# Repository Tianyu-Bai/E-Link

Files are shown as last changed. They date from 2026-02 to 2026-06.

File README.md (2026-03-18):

<div class="lang-en" markdown="1">

<div class="github-only" align="center" style="margin: 40px 0;">
  <a href="https://tianyu-bai.github.io/E-Link">
    
  </a>
  <p style="margin-top: 20px; font-size: 3.5em; font-weight: bold; color: #1e293b;">
    <i>🚀 Click the banner above to interactively rotate, zoom, and explore the internal routing! 🚀</i>
  </p>
</div>

<div align="center">
  <h1 style="border-bottom: none; margin-bottom: 5px; color: #60a5fa; font-size: 2em;">🚀 E-Link(256)</h1>
  
  
</div>

<div align="center" style="margin-top: 15px;">
    
    
    
    
    
  </div>

<br />

<div align="center" class="nav-badges">
  
  
  
  
  
  
</div>

<div align="center">
  <br />
  ELINK-256 Assembly Demo GIF
</div>

<span id="en-overview"></span>
## 📖 Overview

**E-Link** (Elastomer Interconnection-based connector) is an open-source, miniature pedestal connector system based on elastomer interconnection. It provides a robust, scalable interface for flexible neural probes, specifically engineered for chronic applications in freely moving animals.
<div align="center">
 <br>
 E-Link(256) Exploded View
 <p style="margin-top: 5px; font-size: 0.95em; color: #3b82f6;">
   <b>Mating Dynamics (left) and Structural Breakdown (right) of the E-Link(256) </b>
 </p>
</div>

> [!IMPORTANT]
> **Interactive 3D View Available!** > GitHub doesn't support 3D models natively. <a href="https://tianyu-bai.github.io/E-Link">**Click here to interactively rotate, zoom, and explode this assembly directly in your browser!**</a>
---

> [!NOTE]
> **Key Innovation:** The system integrates two high-density PCBs, an anisotropic elastomeric contact interface, and a lightweight pedestal housing into a fully integrated, headstage-ready solution.

---

<span id="en-specs"></span>
### 📊 Quick Specifications

<div align="center">
 <table style="margin-left: auto; margin-right: auto; width: 80%; text-align: center; border-collapse: collapse; border: 1px solid #e1e4e8;">
   <thead>
     <tr style="background-color: #f6f8fa; border-bottom: 2px solid #e1e4e8;">
       <th style="padding: 10px; border: 1px solid #e1e4e8;">Specification</th>
       <th style="padding: 10px; border: 1px solid #e1e4e8;">E-Link(256)_V1.0</th>
     </tr>
   </thead>
   <tbody>
     <tr>
       <td style="padding: 8px; border: 1px solid #e1e4e8;"><b>Channel Count</b></td>
       <td style="padding: 8px; border: 1px solid #e1e4e8;">128 or 256 Channels (Single/Dual SPI Port support)</td>
     </tr>
     <tr>
       <td style="padding: 8px; border: 1px solid #e1e4e8;"><b>Total Mass</b></td>
       <td style="padding: 8px; border: 1px solid #e1e4e8;">6.6 g (with housing)<br>2.8 g (without housing)</td>
     </tr>
     <tr>
       <td style="padding: 8px; border: 1px solid #e1e4e8;"><b>Interconnect Type</b></td>
       <td style="padding: 8px; border: 1px solid #e1e4e8;">Solderless Anisotropic Elastomer</td>
     </tr>
     <tr>
       <td style="padding: 8px; border: 1px solid #e1e4e8;"><b>Compatible Acquisition System</b></td>
       <td style="padding: 8px; border: 1px solid #e1e4e8;">Intan Recording Controller (512ch/1024ch)<br>Open-Ephys DAQ box<br>NeuroNexus Smartbox<br>OmniPlex DAQ box</td>
     </tr>
     <tr>
       <td style="padding: 8px; border: 1px solid #e1e4e8;"><b>Housing Material</b></td>
       <td style="padding: 8px; border: 1px solid #e1e4e8;">3D-Printed PEEK / Surgical Grade Resin</td>
     </tr>
   </tbody>
 </table>
</div>

---

<span id="en-features"></span>
## ✨ Key Features

* **⚡ 256-Channel High-Density & Scalable Interface**<br>
  Compact pedestal footprint supporting 256-ch acquisition. The elastomer-based design offers a clear scaling roadmap (up to 1024-ch) without increasing physical size or surgical overhead.

* **🔌 Zero-Force "Soft" Interconnect**<br>
  By replacing rigid pins with Anisotropic Conductive Elastomer, the system shifts from "insertion" to "compression." This "Gentle yet Firm" philosophy eliminates common failure modes like "bent or broken pins" from the physical level.

* **🎯 Self-Aligning & High Tolerance**<br>
  Features a high-precision mechanical guidance structure with "Structural Redundancy." It naturally forgives minor manual misalignments, ensuring reliable contact with simple rotation — no microscopic alignment required.

* **🛠️ Modular Maintenance & On-Demand Assembly**<br>
  Separable "Sandwich" structure (Housing, Adapter PCB, Headstage). Allows independent replacement of damaged modules and supports on-demand chip soldering (e.g., populating 1, 2, or 4 Intan chips) to save research costs.

* **🪶 Detachable Active Electronics for Unburdened Rest**<br>
  During non-recording periods, the heavy headstage and active electronics can be easily separated from the implanted pedestal. This leaves only a minimal, lightweight passive interface on the skull, significantly 
  reducing the physical payload on the animal and promoting natural behavior between sessions.

* **🐭 Optimized for Chronic In-Vivo Research**<br>
  Ultra-lightweight core (2.8g without housing) and low-profile design. Fully compatible with commutators, ensuring natural behavior and cable management during long-term recording in freely moving animals.

* **🧪 Surgical-Grade Integration & Anatomical Adaptation**<br>
  Features textured sidewalls for superior adhesion with dental cement/UV resin. The base curvature can be customized to match the specific cranial profiles of different animals during 3D printing, ensuring a rock-solid isolation chamber that protects delicate probes from fluids and scratching.
  
<div align="center">
 ELINK-256 Animation GIF
</div>

---

<span id="en-components"></span>
## 🧩 System Components

<div align="center">
 <table border="1" style="border-collapse: collapse; width: 90%; text-align: center;">
   <thead>
     <tr style="background-color: #f2f2f2;">
       <th>Component</th>
       <th>Description</th>
     </tr>
   </thead>
   <tbody>
     <tr>
       <td><b>Pedestal Housing</b></td>
       <td>3D-printed/machined pedestal providing structural support and cranial fixation</td>
     </tr>
     <tr>
       <td><b>Customized 256Ch Headstage</b></td>
       <td>Form-factor optimized recording interface for high-density 128/256-channel signal acquisition</td>
     </tr>
     <tr>
       <td><b>Foam Washer</b></td>
       <td>Provides compliant compression to ensure uniform electrical contact across the elastomeric interface</td>
     </tr>
     <tr>
       <td><b>Adapter PCB</b></td>
       <td>High-density 4-layer PCB for routing signals from thin-film probes to headstage ball array pattern</td>
     </tr>
     <tr>
       <td><b>Surgical Cap</b></td>
       <td>Protective enclosure preserving electrical and mechanical integrity throughout chronic experiments</td>
     </tr>
   </tbody>
 </table>
</div>

---

<span id="en-bom"></span>
### 🛠 Bill of Materials (BOM) of the headstage

<div align="center">
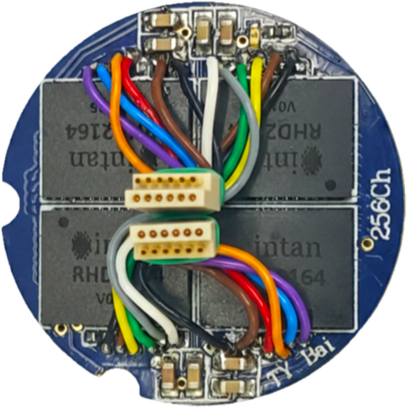
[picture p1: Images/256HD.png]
256Ch Headstage PCBA Assembly
  
  <p style="margin-top: 5px; font-size: 0.9em; color: #64748b;">
    <b>Assembled 256-Channel Headstage (Top View)</b>
  </p>
</div>

<div align="center">
  4-Layer PCB Stackup Explosion
  <p style="margin-top: 5px; font-size: 0.9em; color: #64748b;">
    <b> 4-Layer Routing Structure (Top to Bottom)</b>
  </p>
</div>

> [!TIP]
> **🔍 Inspect the PCB Layers Up Close:** > Want to zoom in on the components or the BGA routing? <a href="https://tianyu-bai.github.io/E-Link">**Visit our interactive website**</a> to view the 3D PCBA model and examine the high-density layout!
<div align="center">
 <table style="margin-left: auto; margin-right: auto; width: 90%; text-align: center; border-collapse: collapse; border: 1px solid #e1e4e8;">
   <thead>
     <tr style="background-color: #f6f8fa; border-bottom: 2px solid #e1e4e8;">
       <th style="padding: 10px; border: 1px solid #e1e4e8; text-align: center;">Component</th>
       <th style="padding: 10px; border: 1px solid #e1e4e8; text-align: center;">Description</th>
       <th style="padding: 10px; border: 1px solid #e1e4e8; text-align: center;">Qty</th>
       <th style="padding: 10px; border: 1px solid #e1e4e8; text-align: center;">Package</th>
       <th style="padding: 10px; border: 1px solid #e1e4e8; text-align: center;">Notes</th>
     </tr>
   </thead>
   <tbody>
     <tr>
       <td style="padding: 8px; border: 1px solid #e1e4e8; text-align: center;"><b>Amplifier IC</b></td>
       <td style="padding: 8px; border: 1px solid #e1e4e8; text-align: center;">Intan RHD2164</td>
       <td style="padding: 8px; border: 1px solid #e1e4e8; text-align: center;">4</td>
       <td style="padding: 8px; border: 1px solid #e1e4e8; text-align: center;">BGA</td>
       <td style="padding: 8px; border: 1px solid #e1e4e8; text-align: center;"><b>Critical:</b> Ensure correct orientation</td>
     </tr>
     <tr>
       <td style="padding: 8px; border: 1px solid #e1e4e8; text-align: center;"><b>SPI Connector</b></td>
       <td style="padding: 8px; border: 1px solid #e1e4e8; text-align: center;">Omnetics A7621</td>
       <td style="padding: 8px; border: 1px solid #e1e4e8; text-align: center;">2</td>
       <td style="padding: 8px; border: 1px solid #e1e4e8; text-align: center;">-</td>
       <td style="padding: 8px; border: 1px solid #e1e4e8; text-align: center;">12-wire cable harness (32 AWG)</td>
     </tr>
     <tr>
       <td style="padding: 8px; border: 1px solid #e1e4e8; text-align: center;"><b>Resistors</b></td>
       <td style="padding: 8px; border: 1px solid #e1e4e8; text-align: center;">Standard SMD</td>
       <td style="padding: 8px; border: 1px solid #e1e4e8; text-align: center;">7</td>
       <td style="padding: 8px; border: 1px solid #e1e4e8; text-align: center;">0402</td>
       <td style="padding: 8px; border: 1px solid #e1e4e8; text-align: center;">LVDS Configuration</td>
     </tr>
     <tr>
       <td style="padding: 8px; border: 1px solid #e1e4e8; text-align: center;"><b>Capacitors</b></td>
       <td style="padding: 8px; border: 1px solid #e1e4e8; text-align: center;">Standard SMD</td>
       <td style="padding: 8px; border: 1px solid #e1e4e8; text-align: center;">8</td>
       <td style="padding: 8px; border: 1px solid #e1e4e8; text-align: center;">0603</td>
       <td style="padding: 8px; border: 1px solid #e1e4e8; text-align: center;">LVDS Configuration</td>
     </tr>
     <tr>
       <td style="padding: 8px; border: 1px solid #e1e4e8; text-align: center;"><b>Power LED</b></td>
       <td style="padding: 8px; border: 1px solid #e1e4e8; text-align: center;">Green LED</td>
       <td style="padding: 8px; border: 1px solid #e1e4e8; text-align: center;">1</td>
       <td style="padding: 8px; border: 1px solid #e1e4e8; text-align: center;">0402</td>
       <td style="padding: 8px; border: 1px solid #e1e4e8; text-align: center;">Power Indicator</td>
     </tr>
     <tr>
       <td style="padding: 8px; border: 1px solid #e1e4e8; text-align: center;"><b>Solder Balls</b></td>
       <td style="padding: 8px; border: 1px solid #e1e4e8; text-align: center;">0.4 mm Lead-free</td>
       <td style="padding: 8px; border: 1px solid #e1e4e8; text-align: center;">~300</td>
       <td style="padding: 8px; border: 1px solid #e1e4e8; text-align: center;">-</td>
       <td style="padding: 8px; border: 1px solid #e1e4e8; text-align: center;">For BGA rework/assembly</td>
     </tr>
   </tbody>
 </table>
</div>

---

## 👥 Developers & Lab

This project is developed by the **MINE Lab** at Dartmouth College. 

* **Tianyu Bai** (Lead Designer) 
* **Gen Li, Ph.D.**
* **Hui Fang, Ph.D.** <a href="https://engineering.dartmouth.edu/community/faculty/hui-fang">

---

## 📄 Publication

This work is currently **under review** at the *IEEE Journal on Flexible Electronics (JFLEX)*.

The hardware designs and visual assets in this repository correspond directly to the system described in the submitted manuscript. To maintain the integrity of the peer-review process:

* **Full Citation**: A permanent link to the final paper will be updated here immediately upon formal acceptance.
* **Preprint/Full Paper**: *Coming Soon.*
  
* We welcome feedback and collaboration from the neuroengineering community!

* **Inquiries**: Thinking about using E-Link in your lab? We know setting up a new system can be tricky. If you have questions about the PCB design or 3D printing, drop us an email or open an issue. We'd love to help you get started!
  * **Email**: [<font color="#60a5fa">support@ephys.tech</font>](mailto:support@ephys.tech)
---

## 📑 Citation & DOI

If you utilize these designs, code, or assets in your research, please cite this repository using the persistent DOI provided by Zenodo:

**Current Reference:**
> T. Bai, et al., "E-Link GitHub Repository," v1.0, MINE Lab, Dartmouth College, 2026. 

---

<span id="en-downloads"></span>
## 🔗 Repository & Downloads

This project is fully open-source. Upon acceptance of the associated paper, the complete dataset comprising **PCB fabrication files (Gerber/NC Drill)**, **BOM**, and **Mechanical CAD** will be accessible via the link below.

<div align="center">
 <p><b>👇 Bookmark the repository for future downloads:</b></p>

<div align="center">
 
 
</div>
</div>

---

## 🤝 Acknowledgments

The developers gratefully acknowledge support from the **NIH (R01MH139342)** and the **Dartmouth PhD Innovation Fellowship**. 

Special thanks to the members of the **MINE Lab** and the **Thayer School of Engineering** for their technical support and feedback throughout the development of the E-Link (256) system.

---

## 📜 License

Copyright © 2026 Tianyu Bai 

This project is open-source and available under the **MIT License**. Click the badge below for full license details.

<div align="center">
 <a href="https://github.com/tianyu-bai/E-Link/blob/main/LICENSE">
   
 </a>
</div>

</div>

<div class="github-only">
  <br>
  <hr>
  <p align="center" style="font-size: 1.5em; font-weight: bold; margin: 20px 0;">
    👇 🇨🇳 Chinese Version / 中文版 👇
  </p>
  <hr>
  <br>
</div>

<div class="lang-zh" markdown="1">

<div class="github-only" align="center" style="margin: 40px 0;">
  <a href="https://tianyu-bai.github.io/E-Link">
    
  </a>
  <p style="margin-top: 20px; font-size: 1.5em; font-weight: bold; color: #1e293b;">
    <i>🚀 点击上方绿色横幅，在浏览器中亲自旋转、缩放，零死角探索 E-Link 细节！ 🚀</i>
  </p>
</div>

<div align="center">
  <h1 style="border-bottom: none; margin-bottom: 5px; color: #60a5fa; font-size: 2em;">🚀 E-Link(易链256)</h1>
  
  Typing SVG
</div>

<div align="center" style="margin-top: 15px;">
    
    
    
    
     
  </div>

  <br />

<div align="center" class="nav-badges">
  
  
  
  
  
  
</div>
  
<div align="center">
  <br />
  ELINK-256 组装演示 GIF
</div>

<span id="cn-overview"></span>
## 📖 概览

**E-Link易链**，是一款基于弹性体互连技术（Elastomer Interconnection）的开源微型基座连接系统。它为柔性神经探针提供了稳固且可扩展的接口，专为自由活动动物的长期慢性实验而优化设计

<div align="center">
  <br>
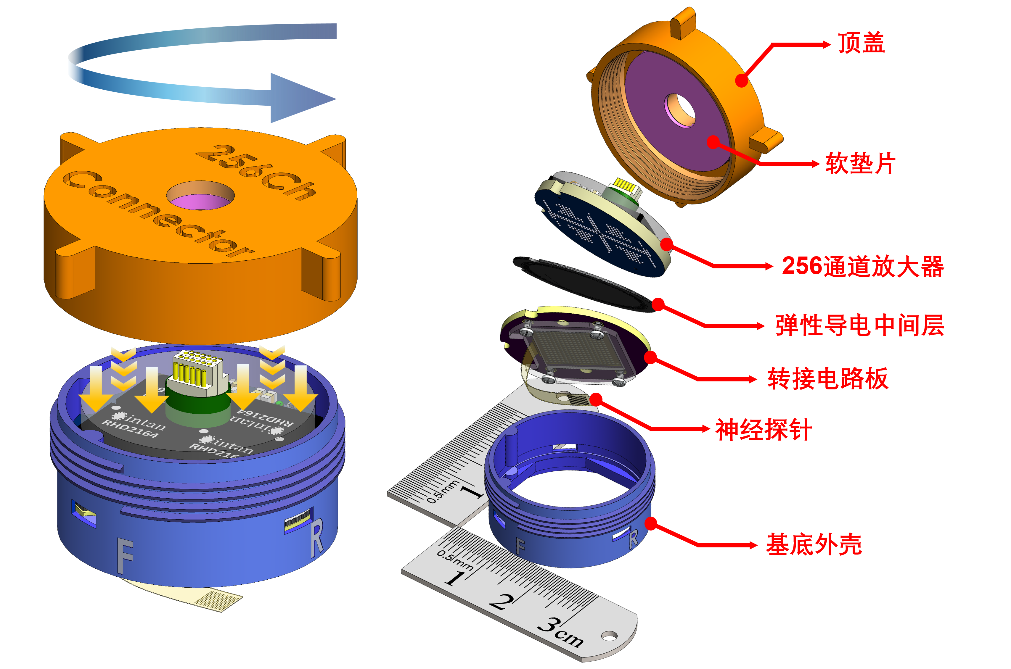
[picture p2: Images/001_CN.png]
E-Link_256 分解图
  
  <p style="margin-top: 5px; font-size: 0.95em; color: ##3b82f6;">
    <b>E-Link易链(256) 的插拔动态（左）和结构分解（右）</b>
  </p>
</div>

> [!IMPORTANT]
> **🎮 支持在线 3D 交互！** > GitHub 原生无法展示 3D 动效。<a href="https://tianyu-bai.github.io/E-Link">**请点击此处前往独立网站，在浏览器中亲自旋转、缩放并拆解此模型！**</a>
---

> [!NOTE]
> **核心创新：** 我们打造了一种完全一体化的 “即拧即用” 数据采集方案。该系统利用弹性导电介质连接高密度 PCB，并封装于轻量级基座中。其最大的突破在于实现了“零力插拔”。免去使用者用力插拔的动作，完美规避了多脚连接器常见的断针和弯针风险。

---

<span id="cn-specs"></span>
### 📊 规格参数

<div align="center">
  <table style="margin-left: auto; margin-right: auto; width: 80%; text-align: center; border-collapse: collapse; border: 1px solid #e1e4e8;">
    <thead>
      <tr style="background-color: #f6f8fa; border-bottom: 2px solid #e1e4e8;">
        <th style="padding: 10px; border: 1px solid #e1e4e8;">规格项目</th>
        <th style="padding: 10px; border: 1px solid #e1e4e8;">E-Link(256)_V1.0</th>
      </tr>
    </thead>
    <tbody>
      <tr>
        <td style="padding: 8px; border: 1px solid #e1e4e8;"><b>通道数</b></td>
        <td style="padding: 8px; border: 1px solid #e1e4e8;">128 或 256 通道 (支持单/双 SPI 端口)</td>
      </tr>
      <tr>
        <td style="padding: 8px; border: 1px solid #e1e4e8;"><b>总质量</b></td>
        <td style="padding: 8px; border: 1px solid #e1e4e8;">6.6 g (含外壳)<br>2.8 g (不含外壳)</td>
      </tr>
      <tr>
        <td style="padding: 8px; border: 1px solid #e1e4e8;"><b>互连类型</b></td>
        <td style="padding: 8px; border: 1px solid #e1e4e8;">免焊各向异性弹性体</td>
      </tr>
      <tr>
        <td style="padding: 8px; border: 1px solid #e1e4e8;"><b>兼容采集系统</b></td>
        <td style="padding: 8px; border: 1px solid #e1e4e8;">Intan Recording Controller (512ch/1024ch)<br>Open-Ephys DAQ box<br>NeuroNexus Smartbox<br>OmniPlex DAQ box</td>
      </tr>
      <tr>
        <td style="padding: 8px; border: 1px solid #e1e4e8;"><b>外壳材料</b></td>
        <td style="padding: 8px; border: 1px solid #e1e4e8;">3D 打印 PEEK / 手术级树脂</td>
      </tr>
    </tbody>
  </table>
</div>

---

<span id="cn-features"></span>
## ✨ 关键特性

* **⚡ 256通道高密度与可扩展接口**<br>
  在有限基座占地面积内实现256通道数据采集。得益于弹性体互连的高集成度，该系统提供了清晰的扩展路径（可达1024通道），且不会增加额外的手术复杂度。

* **🔌 零插拔力，以柔克刚**<br>
  利用各向异性导电弹性体取代传统刚性插针式连接器。通过“旋紧结构”将扭矩转化为均匀压力，从物理层面彻底规避了高密度连接器常见的断针、弯针等失效模式，让连接不再成为系统可靠性的短板。

* **🎯 自对准与高容错连接**<br>
  系统具备优异的机械限位与电气容错率。无需微米级精密对齐，只需简单旋紧即可实现稳定连接，极大降低了手动操作的难度和失败风险。

* **🛠️ 模块化维护与按需组装**<br>
  采用**“三明治”式分离结构**（外壳、适配板、放大器板）。支持损坏模块的单独更换，并允许根据实验通道需求灵活焊接单/多颗芯片，显著降低了科研成本与维护门槛。

* **🪶 电子模块即插即拆，释放动物头部负担**<br>
  在非记录期间，沉重的头件设备与有源电路可与底座快速分离，仅在颅骨留下极轻量的无源底座。这大幅减轻了动物的物理载荷，最大程度保障了动物在实验间隙的自然活动状态。

* **🐭 专为自由活动动物实验优化**<br>
  核心组件仅重 2.8g（移除上盖后）。低剖面设计完美适配换向器 (Commutator)，有效管理线缆并确保动物在长期慢性实验中的自然行为，提升动物福利。

* **🧪 手术级一体化与解剖结构适配**<br>
  侧壁纹理设计极大增强了与牙科水泥或UV树脂的附着力。基座底部的打印弧度可根据不同动物的头部曲线进行定制化调整，从而实现与颅骨的完美贴合，构建出全封闭的防护舱，有效阻隔体液侵蚀并抵抗动物抓挠。

<div align="center">
  ELINK-256 动画演示 GIF
</div>

---

<span id="cn-components"></span>
## 🧩 系统组件

<div align="center">
  <table border="1" style="border-collapse: collapse; width: 90%; text-align: center;">
    <thead>
      <tr style="background-color: #f2f2f2;">
        <th>组件</th>
        <th>描述</th>
      </tr>
    </thead>
    <tbody>
      <tr>
        <td><b>基座外壳</b></td>
        <td>3D 打印/机械加工的基座，提供结构支撑和颅骨固定</td>
      </tr>
      <tr>
        <td><b>定制化 256Ch 头部放大器</b></td>
        <td>针对高密度 128/256 通道信号采集优化的记录接口</td>
      </tr>
      <tr>
        <td><b>泡沫垫圈</b></td>
        <td>提供柔性压缩层，确保弹性导电基体上方的电气接触均匀</td>
      </tr>
      <tr>
        <td><b>转接PCB</b></td>
        <td>高密度 4 层 PCB，用于将信号从薄膜探针路由到放大器的球栅阵列图案转换</td>
      </tr>
      <tr>
        <td><b>手术保护盖</b></td>
        <td>保护性外壳，在长期慢性实验中保持电气和机械完整性</td>
      </tr>
    </tbody>
  </table>
</div>

---

<span id="cn-bom"></span>
### 🛠 放大器物料清单 (BOM)

<div align="center">
  256通道放大器组装实物图
  <p style="margin-top: 5px; font-size: 0.9em; color: #64748b;">
    <b>已组装的 256 通道前置放大器 (顶视图)</b>
  </p>
</div>

<div align="center">
  顶部4层电路板的设计爆炸动图
  <p style="margin-top: 5px; font-size: 0.9em; color: #64748b;">
    <b> 顶部4层电路板的设计爆炸动图 </b>
  </p>
</div>
    
> [!TIP]
> **🔍 在线放大查看 PCB 细节：** > 想要放大看清 0402 贴片或者 BGA 走线？<a href="https://tianyu-bai.github.io/E-Link">**访问我们的交互网站**</a>，即可在浏览器中与 3D 放大器模型互动，极其清晰地观察高密度布局！
<div align="center">
  <table style="margin-left: auto; margin-right: auto; width: 90%; text-align: center; border-collapse: collapse; border: 1px solid #e1e4e8;">
    <thead>
      <tr style="background-color: #f6f8fa; border-bottom: 2px solid #e1e4e8;">
        <th style="padding: 10px; border: 1px solid #e1e4e8; text-align: center;">组件</th>
        <th style="padding: 10px; border: 1px solid #e1e4e8; text-align: center;">描述</th>
        <th style="padding: 10px; border: 1px solid #e1e4e8; text-align: center;">数量</th>
        <th style="padding: 10px; border: 1px solid #e1e4e8; text-align: center;">封装</th>
        <th style="padding: 10px; border: 1px solid #e1e4e8; text-align: center;">备注</th>
      </tr>
    </thead>
    <tbody>
      <tr>
        <td style="padding: 8px; border: 1px solid #e1e4e8; text-align: center;"><b>放大器 IC</b></td>
        <td style="padding: 8px; border: 1px solid #e1e4e8; text-align: center;">Intan RHD2164</td>
        <td style="padding: 8px; border: 1px solid #e1e4e8; text-align: center;">4</td>
        <td style="padding: 8px; border: 1px solid #e1e4e8; text-align: center;">BGA</td>
        <td style="padding: 8px; border: 1px solid #e1e4e8; text-align: center;"><b>关键：</b> 确保方向正确</td>
      </tr>
      <tr>
        <td style="padding: 8px; border: 1px solid #e1e4e8; text-align: center;"><b>SPI 连接器</b></td>
        <td style="padding: 8px; border: 1px solid #e1e4e8; text-align: center;">Omnetics A7621</td>
        <td style="padding: 8px; border: 1px solid #e1e4e8; text-align: center;">2</td>
        <td style="padding: 8px; border: 1px solid #e1e4e8; text-align: center;">-</td>
        <td style="padding: 8px; border: 1px solid #e1e4e8; text-align: center;">12 线线束 (32 AWG)</td>
      </tr>
      <tr>
        <td style="padding: 8px; border: 1px solid #e1e4e8; text-align: center;"><b>电阻</b></td>
        <td style="padding: 8px; border: 1px solid #e1e4e8; text-align: center;">标准贴片</td>
        <td style="padding: 8px; border: 1px solid #e1e4e8; text-align: center;">7</td>
        <td style="padding: 8px; border: 1px solid #e1e4e8; text-align: center;">0402</td>
        <td style="padding: 8px; border: 1px solid #e1e4e8; text-align: center;">LVDS 配置</td>
      </tr>
      <tr>
        <td style="padding: 8px; border: 1px solid #e1e4e8; text-align: center;"><b>电容</b></td>
        <td style="padding: 8px; border: 1px solid #e1e4e8; text-align: center;">标准贴片</td>
        <td style="padding: 8px; border: 1px solid #e1e4e8; text-align: center;">8</td>
        <td style="padding: 8px; border: 1px solid #e1e4e8; text-align: center;">0603</td>
        <td style="padding: 8px; border: 1px solid #e1e4e8; text-align: center;">LVDS 配置</td>
      </tr>
      <tr>
        <td style="padding: 8px; border: 1px solid #e1e4e8; text-align: center;"><b>电源 LED</b></td>
        <td style="padding: 8px; border: 1px solid #e1e4e8; text-align: center;">绿色 LED</td>
        <td style="padding: 8px; border: 1px solid #e1e4e8; text-align: center;">1</td>
        <td style="padding: 8px; border: 1px solid #e1e4e8; text-align: center;">0402</td>
        <td style="padding: 8px; border: 1px solid #e1e4e8; text-align: center;">自检状态灯</td>
      </tr>
      <tr>
        <td style="padding: 8px; border: 1px solid #e1e4e8; text-align: center;"><b> 标注锡球 </b></td>
        <td style="padding: 8px; border: 1px solid #e1e4e8; text-align: center;">0.4 mm 无铅</td>
        <td style="padding: 8px; border: 1px solid #e1e4e8; text-align: center;">约300</td>
        <td style="padding: 8px; border: 1px solid #e1e4e8; text-align: center;">-</td>
        <td style="padding: 8px; border: 1px solid #e1e4e8; text-align: center;">用于 BGA 组装</td>
      </tr>
    </tbody>
  </table>
</div>

---

## 👥 开发者与实验室

本项目由达特茅斯学院 **Fang课题组** 开发。

* **白天宇** (主导研发及设计) 
* **李根**
* **方辉教授** <a href="https://engineering.dartmouth.edu/community/faculty/hui-fang">

---

## 📄 出版物

本工作目前正在 **IEEE Journal on Flexible Electronics (JFLEX)** 审稿中。

本仓库中的硬件设计和视觉资产直接对应于投稿中描述的系统。

* **完整引用**：正式录用后，最终论文的永久链接将立即在此处更新。
* **预印本/全文**：*即将推出。*
  
* 我们欢迎神经工程科研社区的反馈与合作！

* **咨询**：如需获取技术设计文件或有任何相关疑问，请邮件联系：
   * **技术支持**: [<font color="#60a5fa">support@ephys.tech</font>](mailto:support@ephys.tech)

---

## 📑 引用与 DOI

如果您在研究中使用了这些设计、代码或资产，请使用 Zenodo 提供的永久 DOI 引用本仓库：

**当前参考：**
> T. Bai, et al., "E-Link GitHub Repository," v1.0, MINE Lab, Dartmouth College, 2026. 

---

<span id="cn-downloads"></span>
## 🔗 仓库与下载

本项目完全开源。相关论文录用后，包含 **PCB 制造文件 (Gerber/NC Drill)** 和 **3D打印文件** 的完整数据集将通过以下链接提供访问。

<div align="center">
  <p><b>👇 欢迎收藏本仓库以便未来下载：</b></p>

<div align="center">
  
  
</div>
</div>

---

## 🤝 致谢

开发者衷心感谢 **美国国立卫生研究院 NIH R01MH139342** 和 **达特茅斯博士生创新奖学金 (Dartmouth PhD Innovation Fellowship)** 的支持。

特别感谢 **达特茅斯Thayer工学院** 的相关成员在易链系统开发过程中提供的技术支持和反馈。

---

## 📜 许可协议

版权所有 © 2026 Tianyu Bai 

本项目为开源硬件，在以下许可下可用。点击下方徽章查看完整许可详情。

* **硬件源文件** (KiCad/Gerbers/STL 文件)：在 **MIT 许可** 下授权。
* **文档、原理图 (PDF) 和图像**：在 **CC BY 4.0 国际许可** 下授权。

<div align="center">
  <a href="https://github.com/tianyu-bai/E-Link/blob/main/LICENSE">
    
  </a>
</div>

</div>

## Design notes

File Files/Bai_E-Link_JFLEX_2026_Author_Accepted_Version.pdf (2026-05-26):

IEEE JOURNAL ON FLEXIBLE ELECTRONICS, VOL. X, NO. X, MONTH YEAR

# E-Link: A 256-ch Mini-Pedestal Connector for High-Density Soft Neural Interfaces

Tianyu Bai, Gen Li, Yongli Qi, and Hui Fang

Abstract—High-density thin-film neural interfaces face persistent packaging challenges at the electrode–electronics interface, where conventional rigid connectors impose high insertion forces, strict alignment requirements, and limited reusability. We present E-Link (Elastomeric Link), a modular 256-channel mini-pedestal connector designed to facilitate simplified, user-friendly assembly through an insertion-free, alignment-tolerant interface utilizing an elastomeric conductive interposer and a compliant threaded compression mechanism. Finite element analysis and experimental validation confirm uniform contact stress across the 16 × 16 interconnect array. The system achieves stable electrical performance, exhibiting contact impedances of 0.3-0.4 kΩ, an RMS noise floor of 2.68 ± 0.46 μV, and a connection yield exceeding 97% over 100 mating cycles. The detachable architecture reduces chronic head-mounted mass from

### 6.6 g to 2.8 g while maintaining safe thermal operation (30.5 °C

steady-state) under a full 20 kHz sampling bandwidth. Design analysis further indicates scalability toward 1024-channel integration within the same 25-mm-diameter footprint by leveraging fine-pitch elastomeric conductive pillars. This work provides a robust and scalable connection solution for high-density flexible neural interfaces with broad application for bioelectronics.

Index Terms—Elastomeric conductive interposer, high-density interconnects, low-noise neural recording, neural implants, thin-film microelectrode arrays.

I. INTRODUCTION
HE development of thin-film, polymer-based neural interfaces has fundamentally advanced neural recording and stimulation by enabling high spatial resolution and improved biocompatibility, aligning closely with the core objectives of flexible electronics and microsystems for chronic biointegration. These flexible interfaces, including
electrocorticography | (ECoG) | arrays, | intracortical
microelectrode arrays, and peripheral nerve interfaces, have become indispensable devices and tools for brain–computer interfaces (BCIs), systems neuroscience, and translational neuroengineering [1].
As neural interface technologies mature, the field is rapidly progressing toward high-channel-count systems (hundreds to thousands of channels and beyond), driven by demands for higher information throughput, improved decoding accuracy, and

Manuscript received Jan 31, 2026; revised Mar 27, 2026; accepted xxx xx, 2026. Date of publication xxx xx, 2026; date of current version xxx xx, 2026. This work was supported in part by the National Institutes of Health under Grant R01MH139342 and in part by the Dartmouth PhD Innovation Fellowship. (Corresponding author: Hui Fang).
The authors are with the Multifunctional Integrated NeuroElectronics (MINE) Lab, Thayer School of Engineering, Dartmouth College, Hanover, NH 03755 USA (e-mail: hui.fang@dartmouth.edu).

increased precision in therapies [1], [2]. While substantial efforts have optimized electrode materials, geometries, and surface chemistries, long-term system performance is no longer limited only by the electrode–tissue interface [3]. Instead, another dominant bottleneck for chronic deployment now resides at the system-integration level, specifically, in the mechanical and electrical packaging that bridges soft, high-density neural electrodes with rigid signal-processing electronics.
This soft–hard interface presents a uniquely challenging engineering problem. Flexible thin-film electrodes are mechanically soft, highly deformable, and highly sensitive to misalignment, whereas backend electronics demand stable, repeatable, and low-impedance electrical connections. In practice, failures at this interface frequently dictate overall system lifetime, even when the implanted electrode array remains electrically functional. Consequently, connector reliability, mechanical compliance, and modularity have emerged as critical, yet often underappreciated, determinants of chronic neural recording success.
Conventional approaches for interfacing high-channel-count neural probes with electronic headstages rely predominantly on micro-miniature rigid connectors, such as Omnetics or Hirose series [4], [5]. These pin-based connectors provide excellent electrical performance at modest channel counts and have become the established industry standard for acute and short-term experiments. However, their scalability is fundamentally constrained. As channel count increases, the required insertion force rises proportionally, substantially elevating the risk of mechanical damage to thin-film traces, solder joints, or cranial mounting structures. Moreover, the reliance on precise pin-tosocket alignment renders these connectors highly susceptible to failure from even sub-millimeter misalignment, leading to bent pins, intermittent contacts, or catastrophic shorts.
Beyond alignment and insertion force limitations, the rigid, bulky form factors of traditional connectors introduce additional challenges for chronic implantation. Increased connector height and head-mounted mass amplify bending moments at the implant site and increase skin strain, potentially leading to skin erosion, infection, and implant instability. In freely behaving animal models, excessive head-mounted weight has been shown to alter natural behaviors and introduce

The complete structure and the intuitive mating process are further illustrated in Video S1 (animated full-rotation structural overview) and Video S2 (assembly/disassembly procedures) in the supplemental materials.
All design files, fabrication documentation, and assembly instructional videos supporting this work are available in an open-source repository on GitHub at https://github.com/Tianyu-Bai/E-Link
Digital Object Identifier xx.xxxx/JFLEX.2026.xxxxxxx

T

This article has been accepted for publication in IEEE Journal on Flexible Electronics. This is the author's version which has not been fully edited and content may change prior to final publication. Citation information: DOI 10.1109/JFLEX.2026.3692102

© 2026 IEEE. All rights reserved, including rights for text and data mining and training of artificial intelligence and similar technologies. Personal use is permitted, but republication/redistribution requires IEEE permission. See https://www.ieee.org/publications/rights/index.html for more information.

Authorized licensed use limited to: Dartmouth Libraries. Downloaded on May 26,2026 at 22:25:35 UTC from IEEE Xplore. Restrictions apply.

motion-related artifacts that degrade recording quality [6]. Collectively, these limitations restrict the practicality of rigid connectors for long-term, high-density neural recording.
To reduce the mechanical footprint of rigid connectors, several low-profile interconnection strategies have been explored, including anisotropic conductive film (ACF) bonding and direct ultrasonic or thermocompression welding to amplifier boards [7], [8], [9]. While these approaches reduce connector height and eliminate pin-alignment requirements, they introduce distinct trade-offs. Most notably, they are inherently permanent or semi-permanent, precluding routine detachment of backend electronics from the implanted electrode array. This lack of modularity hinders the reuse of
costly | signal-processing | hardware | and | complicates
maintenance, troubleshooting, and system upgrades [4]. In many cases, failure of a single interconnect necessitates replacing the entire implanted array, increasing experimental costs and animal burden.
Existing | interconnection | strategies | thus | expose | a
fundamental limitation in chronic neural interface design towards achieving simultaneously high channel density, low electrical noise, mechanical compliance, and modular reusability at the soft–hard interface. An ideal solution must tolerate mechanical misalignment, minimize insertion forces, distribute contact stress uniformly across fragile thin-film electrodes, and support repeated connection cycles without degradation of electrical performance, all while maintaining a compact, lightweight form factor suitable for chronic implantation [10].
In this work, we present a modular 256-channel mini-pedestal connector that addresses these challenges through an insertion-free, alignment-tolerant interconnection architecture specifically designed for flexible neural interfaces. The system employs an elastomeric conductive interposer combined with a compliant threaded compression mechanism to achieve uniform, low-impedance electrical contact across a 16 × 16 channel array without precision pin alignment or permanent bonding. Through finite element modeling and
comprehensive | electrical, | thermal, | and | mechanical
characterization, | we | demonstrate | stable | low-noise
performance, robust durability over repeated mating cycles, and reduced chronic head-mounted mass. The underlying design principles further support scalability toward higher channel counts, providing a generalizable packaging framework for next-generation flexible bioelectronic systems.

II. SYSTEM ARCHITECTURE AND MECHANICAL DESIGN

A. Modular Mini-Pedestal Design Concept
The proposed 256-channel connector is designed as a modular mini-pedestal-and-cap architecture that decouples the mechanically fragile electrode–tissue interface from the comparatively heavy signal-processing electronics [11]. As illustrated in the exploded view in Fig. 1(a), the assembly comprises a threaded mini-pedestal (➇) affixed to the surgical site, which houses both the adapter printed circuit board (PCB) (➅) and the polymer-based neural interface (➆).

A customized 256-channel headstage (➃) is positioned above the mini-pedestal and electrically interfaced through a conductive pillar–embedded elastomeric interposer (➄), enabling insertion-free, high-density electrical contact. The entire assembly is mechanically secured by a threaded cap (➀) integrated with a compliant foam washer (➁), which provides controlled compression and ensures stable mechanical interlocking under repeated attachment cycles.
This modular configuration is a critical design feature for chronic implantation. By allowing the headstage electronics to be detached during non-recording periods, the system reduces the head-mounted mass from 6.6 g to 2.8 g, thereby minimizing chronic mechanical load on the implant site, reducing biological stress, and enabling efficient reuse of backend recording hardware.
B. Mechanical Interlocking and Compression Strategy
The mechanical reliability of the 256-channel interface is enabled by a controlled compression strategy that eliminates the need for conventional high-density pin-based connectors, which are inherently susceptible to misalignment and mechanical damage. As illustrated in the cross-sectional view in Fig. 1(b), the system leverages the mechanical advantage of a threaded interface to achieve secure and repeatable electrical interconnection.
In this configuration, the adapter PCB (➅) is precisely seated on an internal step within the mini-pedestal (➇), establishing a well-defined axial reference plane. When manual torque is applied to the threaded cap (➀), a uniform downward axial force is generated and transmitted through a compliant foam washer (➁) to the customized headstage (➃). To ensure long-term electronic reliability, headstage components interfacing with the foam washer are encapsulated with a transparent, waterproof potting compound that mechanically isolates sensitive circuitry and enables uniform pressure distribution. The applied axial compression uniformly compresses the elastomeric conductive interposer (➄), thereby establishing stable, insertion-free electrical connections between the headstage (➃) and the adapter PCB (➅). This approach is optimally designed for chronic neural implants, as it provides a robust, self-aligning mating mechanism that preserves signal integrity across hundreds of channels while avoiding the high insertion forces associated with rigid plug-based connectors. The cross-sectional architecture further incorporates a dedicated floating cavity to accommodate the elastomeric interposer (➄). As the headstage PCB is driven downward by the threaded cap, this cavity allows controlled compression of the elastomer between the two PCB planes. To standardize compression without external tools, engineered thread positions provide a visual calibration, aligning explicit 'F' (Front) and 'R' (Right) marks on the housing for optimal mating (Fig. 1). In combination with the mini-pedestal step that constrains the adapter PCB, this structural arrangement ensures uniform contact pressure and consistent electrical engagement across the full channel array. Collectively, these features yield a compliant
interconnection | architecture | that | tolerates | positional
misalignment and supports long-term, high-density neural recording.

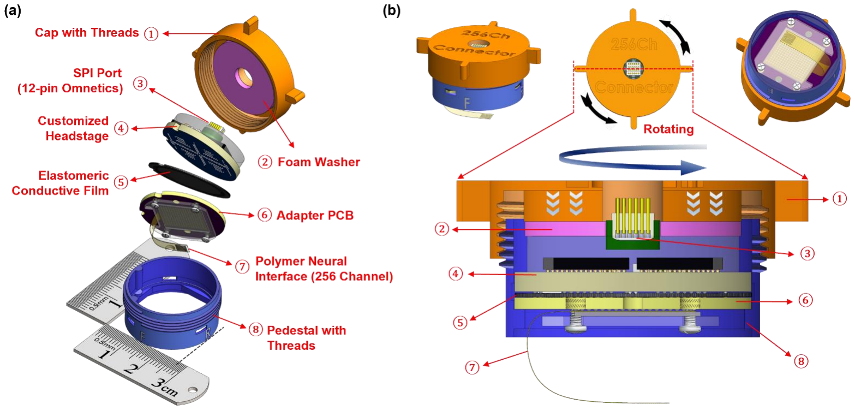
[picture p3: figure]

C. Thin-Film Probe and Adapter Board Sandwich Integration The transition from the flexible polyimide thin-film probe to the rigid adapter PCB is realized through a precisionengineered sandwich assembly, as highlighted in the upperright detail of Fig. 1(b). To maintain an ultra-low-profile form factor and ensure a flush mechanical interface, four M1.2 micro-knurled nuts with a height of 1.0 mm are press-fitted into pre-drilled apertures (1.18 mm in diameter) on the 1.2 mm thick adapter PCB. This specific tolerance allows the nuts to be fully recessed within the PCB substrate, eliminating vertical protrusions that could interfere with overall headstage seating. The structural transition is anchored by a precision sandwich assembly comprising a 1/32-inch thick transparent acrylic clamping plate and a high-compliance silicone rubber cushion [2], [12]. This assembly is secured to the rigid adapter PCB using four lightweight M1.2 Phillips-head screws, facilitating a straightforward integration process with standard micro-tools. The clamping plate incorporates a precision-machined notch that serves a dual purpose: it guides the initial routing of the thin-film probe. It acts as a strategic folding point for strain relief, thereby preserving trace integrity during chronic recording. Concurrently, the silicone rubber layer serves as a conformal buffer, compensating for micro-scale surface irregularities and ensuring uniform contact pressure and intimate electrical engagement between the probe's electrode pads and the PCB contacts.

III. CIRCUIT IMPLEMENTATION AND ROUTING STRATEGY

A. Headstage Circuit Architecture and Signal Flow
The recording performance of the proposed mini-pedestal connector is enabled by a custom 256-channel headstage
specifically | optimized | for | high-density | neural | signal
acquisition. As illustrated in Fig. 2, neural signals are processed through a hierarchical signal chain that preserves signal fidelity from the electrode–tissue interface to digitization.
The headstage integrates four Intan RHD2164 analog front-end (AFE) integrated circuits (ICs), designated as chips #1–#4. Each AFE incorporates a 64-channel low-noise amplifier array, 32:1 multiplexers, and on-chip 16-bit analog-to-digital converters (ADCs), collectively enabling simultaneous acquisition from 256 recording channels [13].
To accommodate the high aggregate data throughput at the system's nominal sampling rate of 20 kHz, the headstage architecture is partitioned into two 128-channel Serial Peripheral Interface (SPI) groups, designated Port I and Port II. Port I interfaces with chips #1 and #2, while Port II interfaces with chips #3 and #4. This parallelized communication scheme reduces SPI bus loading and ensures stable, high-speed data transfer without compromising timing margins.
Ensuring | signal | integrity | across | electrically | noisy
environments is a fundamental requirement for implantable recording platforms. To this end, low-voltage differential signaling (LVDS) is employed for critical communication pathways between the headstage and the controller. The use of differential signaling for chip select (CS̅̅̅), serial clock (SCLK), and master-out–slave-in (MOSI) lines provide robust commonmode noise rejection while effectively decoupling high-speed digital switching from the sensitive microvolt-level analog front end [14]. Such a configuration ensures high-performance digital communication without compromising the noise floor of the neural signal acquisition system.

Fig. 1. System design concept and mechanical integration strategy. (a) Exploded-view schematic illustrating the assembly components of the modular 256-channel pedestal connector. The system integrates a polymer neural interface with a customized headstage using an elastomeric interposer. (b) Fully assembled connector: side view (top left), top view (top middle), and bottom view (top right). The bottom panel provides a cross-sectional view of the threaded compression mechanism. The housing design converts manual torque into uniform axial pressure, facilitating stable electrical interlocking between the adapter PCB which is fixed on the internal pedestal step and headstage contacts without the need for precision pin alignment.

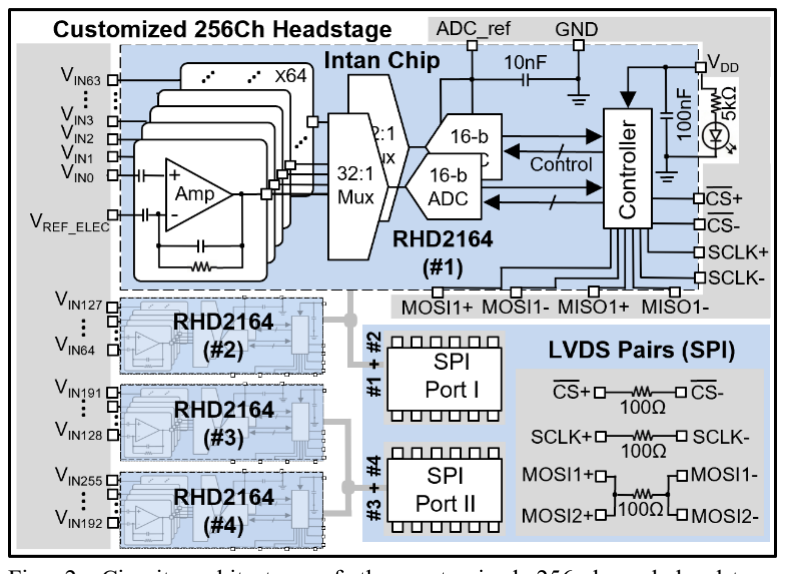
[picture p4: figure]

Fig. 2. Circuit architecture of the customized 256-channel headstage. Functional block diagram showcasing the hierarchical signal flow from the neural electrodes (256 channels) to the digital controller. The architecture integrates four RHD2164 analog front-end chips (#1 to #4), each featuring a 64-channel amplifier array, 32:1 multiplexers, and 16-bit ADCs. The front-end is organized into two independent 128-channel SPI groups (Port I and Port II).

To mitigate transient current loads during simultaneous 16-bit ADC switching across the four RHD2164 chips, a localized decoupling strategy is employed. 10 nF and 100 nF bypass capacitors are positioned adjacent to the VDD pins of each controller to minimize trace inductance and supply instantaneous high-frequency currents. This local decoupling is augmented by continuous internal power and ground planes within the four-layer stackup, which provide distributed interplane capacitance and low-impedance return paths. These measures suppress transient voltage drop and cross-band noise, facilitating stable signal acquisition across the analog front-end.

B. Headstage Layer Stack
The physical realization of the 256-channel headstage prioritizes extreme miniaturization without compromising signal quality. As shown in Fig. 3(a), the headstage is implemented on a high-density, four-layer PCB with a compact circular footprint of 25 mm in diameter. To ensure precise mechanical seating and facilitate hardware reuse, the PCB features two arc-shaped alignment notches. The headstage is keyed to the pedestal housing through these notches to prevent rotation during cap tightening. The arc-shaped profile was deliberately chosen over triangular notches to minimize surface wear and friction during repeated mating cycles.
The four-layer stackup (L1–L4, Fig. S1) is optimized to manage dense 256-channel routing within a 25-mm footprint while ensuring signal integrity. Layer 1 (top) hosts the analog front-end ICs and miniaturized passives. To minimize digital-to-analog crosstalk, critical high-speed SPI communication lines are buried within the inner layers: Layer 2 carries differential CS and SCLK pairs shielded by ground (GND) copper pours, while Layer 3 routes differential MOSI pairs and distributes Power (VDD). Layer 4 (bottom) serves as a continuous GND plane to ensure stable signal return paths and

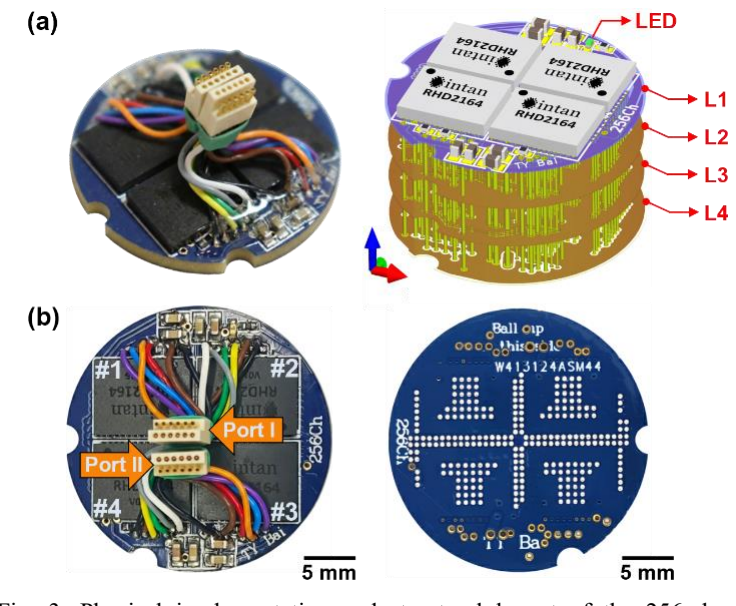
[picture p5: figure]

Fig. 3. Physical implementation and structural layout of the 256-channel headstage. (a) Photograph of the fully assembled 256-channel headstage (left) and its 3D structural layout (right), highlighting the integrated shielding and the stacked functional layers (L1–L4). (b) Detailed view of the PCB top side (left) showing the placement of four symmetrically arranged RHD2164 chips (#1 to #4) and Port I/II connectors, alongside the bottom side (right) featuring the high-density ball grid array (BGA) array for insertion-free elastomeric interfacing.

accommodates the high-density BGA elastomeric interface. On the top layer, the four RHD2164 chips are arranged in a symmetric configuration, with chips #1/#2 forming one pair and chips #3/#4 forming the second [Fig. 3(b)]. The reference (REF) pins of each chip pair are shorted and tied to a common system ground to ensure baseline consistency across the electrode array. To achieve high component density, the design employs ultra-miniaturized 0402-size surface-mount resistors and 0603-size capacitors. A green 0402 LED is integrated into the top layer as a real-time power indicator.
For data transmission, the system utilizes two 12-pin Omnetics A79621 connectors positioned at the center of the headstage. This central placement provides a significant mechanical advantage: as the threaded cap rotates during assembly, the wire bundles—organized and secured by heatshrink tubing—pass directly through the circular aperture in the cap's center. This configuration ensures that the wires do not interfere with the mechanical housing or undergo twisting during rotation, effectively isolating the delicate interconnects from rotational torque.
Furthermore, the central connector placement facilitates a spatial star-grounding topology. To avoid the electromagnetic interference (EMI) loop antennas often cause when split analog/digital planes are used, the system utilizes a unified, continuous ground plane. This configuration promotes a compact return-current path near the connector region, reducing the likelihood of digital switching noise coupling into peripheral analog traces. Impressively, despite housing 256 channels and supporting electronics, the PCBs weigh merely 2.8 g. This ultra-lightweight profile substantially mitigates mechanical loading at the surgical site compared to conventional commercial systems.

C. Mechanical Interface Characterization and Interconnect Reliability
To evaluate the reliability of the proposed insertion-free mating system, we performed a comprehensive morphological and mechanical characterization of the anisotropic conductive elastomer interposer, as its material behavior fundamentally dictates the stability and repeatability of neural signal acquisition across the 256-channel interface. This component consists of a high-density array of conductive pillars embedded within a compliant elastomeric matrix, functioning as a microscale mechanical and electrical bridge between the headstage and the adapter PCB.
Morphological characterization, as depicted in Fig. 4, reveals a uniform hexagonal arrangement of conductive pillars characterized by an average diameter of 105 μm and a height of 385 μm. These vertically aligned microstructures establish independent conductive pathways between the ball grid array multichannel interconnections through surface contact while obviating the need for rigid, alignment-sensitive precision pins. The interfacial compressive mechanics were investigated through correlated experimental observations and finite element analysis (FEA), with a specific focus on tolerance to pitch mismatch and misalignment. In the uncompressed state, the conductive pillars exert minimal contact force and exhibit negligible internal stress. Upon application of manual torque through the threaded cap—resulting in an initial elastomeric compression of 5%—the pillars establish firm seating against the PCB pads. At this stage, a uniform von Mises stress distribution develops across the contact regions, marking the initiation of stable electrical engagement.
Under increased axial compression (20% strain), the conductive pillars undergo controlled elastic deformation, which substantially expands the effective electrical contact area. FEA simulations corroborate that peak stress localizes primarily at the upper and lower contact interfaces of the pillars, while the elastomeric matrix ensures a uniform strain distribution across the array. This strategic stress localization promotes the formation of low-impedance conductive pathways while mitigating excessive mechanical loading that could compromise long-term interface reliability.
The robust alignment tolerance of the interconnect is achieved through a deliberate overprovisioning strategy, where the conductive pillar density significantly exceeds that of the PCB contact pads. This structural redundancy ensures that multiple pillars bridge each electrode-pad interface, thereby preserving stable electrical connectivity across all 256 channels even under moderate radial misalignment between the headstage and adapter PCBs. Together, these design features
yield | a | compliant, | alignment-tolerant | interconnection
architecture that supports reliable electrical connectivity in high-density chronic neural recording systems.
D. Adapter PCB Design and Routing Strategy
The adapter PCB (Fig. 5) serves as the foundational interface within the mini-pedestal, bridging the high-density connection from the polymer neural interface to the modular headstage. To

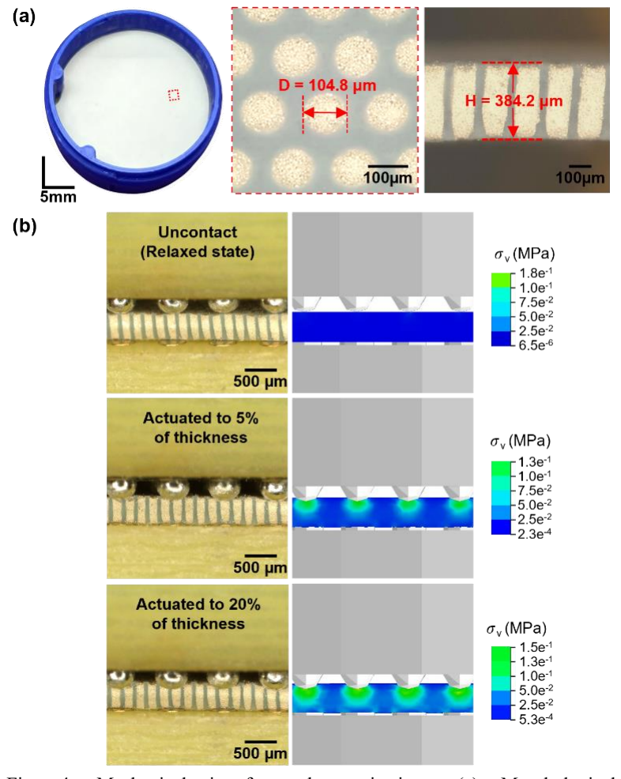
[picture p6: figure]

Fig. | 4. | Mechanical | interface | characterizations. | (a) | Morphological
characterization of a conductive pillar-embedded elastomer sheet: microscopic analysis of the top-view distribution and cross-sectional profile. (b) Mechanical response and stress distribution of alignment-free conductive pillar interfaces with pitch mismatch: microscopic photographs and corresponding FEA stress simulations of the elastomer in the relaxed state, 5% compression, and 20% compression.

accommodate 256 independent signal channels within a confined circular area, we implemented a four-layer fan-out architecture with vertical blind vias that transit signals between layers while minimizing lateral routing space. This strategy enables a routing pitch significantly finer than standard through-hole or ball grid array configurations, which is essential for achieving the required channel density.
The top surface of the adapter PCB features a high-density pad array [Fig. 5(a), left] specifically optimized to interface with the conductive pillar-embedded elastomer. To maximize insertion-free contact reliability, no solder mask is applied to the top layer, allowing the gold-plated pads to remain elevated above the PCB surface. This protruding profile ensures intimate mechanical engagement and stable electrical contact with the conductive pillars under axial compression.
The bottom layer of the adapter PCB features a high-density BGA footprint [Fig. 5(a), right] optimized for direct coupling with the polymer neural interface, thereby facilitating a seamless, low-impedance signal transition from the electrodes to the backend electronics. Signals are distributed through the four-layer stackup using blind vias [Fig. 5(b)] for vertical interconnects, effectively managing crosstalk and maintaining signal fidelity across the full recording bandwidth. The entire

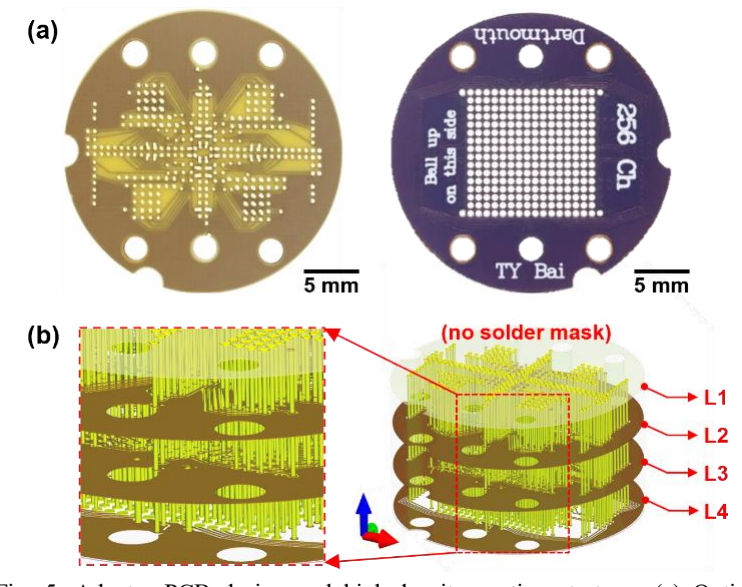
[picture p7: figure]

Fig. 5. Adapter PCB design and high-density routing strategy. (a) Optical photographs of the adapter PCB. The top side (left) features a 256-channel gold pad array designed without a solder mask on the top side of the first layer, allowing the gold-plated pads to remain extruded from the surface to facilitate intimate mechanical engagement with the elastomeric conductive pillars. The bottom side (right) features a high-density 256-channel BGA array for interface integration. (b) 3D exploded view illustrating the 4-layer fan-out architecture and the implementation of vertical interconnects using blind vias.

adapter assembly seats securely on an internal shoulder within the mini-pedestal housing, providing mechanical stability for the rotational compression mechanism.
Beyond | spatial | efficiency, this | multi-layer | routing
architecture orchestrates a critical geometric remapping by translating the application-specific, often non-uniform fan-out patterns of the flexible probe into a standardized, symmetric pad matrix on the top layer. The design resolves the routing complexity inherent in converting irregular electrode footprints into a repeatable, high-density grid. This architectural transformation ensures that the 256-channel array is condensed into a compact, uniform layout suitable for elastomeric interfacing, while strictly adhering to manufacturing design rules for trace width and spacing clearances.

IV. EXPERIMENTAL RESULTS AND CHARACTERIZATION

A. Contact Impedance Characterization
To validate the electrical reliability of the 256-channel insertion-free interface, we performed spatial impedance mapping using a gold film test interface [Fig. 6(a)]. As illustrated in the 16 × 16 heatmap in Fig. 6(b), the system achieves remarkable uniformity across the high-density array. The majority of channels demonstrate contact impedance within the range of 0.3-0.4 kΩ. This high degree of uniformity confirms that the threaded housing assembly, which converts manual torque into uniform axial pressure, successfully distributes the controlled load across the adapter PCB's entire 25-mm footprint. Three specific channels exhibited impedance exceeding 1.0 kΩ. These three channels were identified as nonfunctional due to inherent hardware defects originating from the high-density chip-to-PCB soldering process during headstage fabrication, specifically related to sub-optimal reflow of the

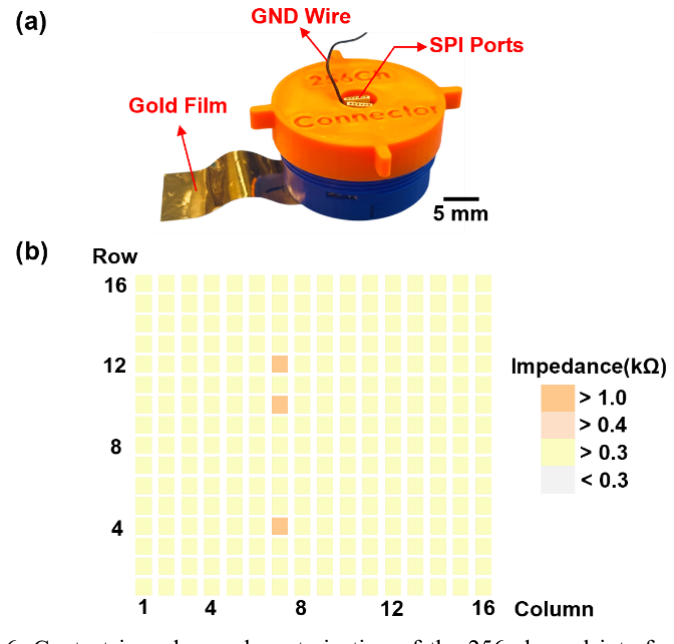
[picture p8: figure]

Fig. 6. Contact impedance characterization of the 256-channel interface. (a) Photograph of the mini-pedestal connector integrated with a gold film for contact validation. (b) 16×16 spatial heatmap illustrating the contact impedance distribution.

0.3-mm-pitch BGA pins, rather than failure of the mechanical connector interface itself.

B. FEA Validation
To provide a theoretical foundation for the observed electrical consistency, we conducted FEA to evaluate the mechanical behavior of the 256-channel interface under operational loads. The simulation specifically modeled the structural response during 20% thickness compression of the anisotropic conductive elastomer, corresponding to the typical displacement achieved by threaded manual assembly.
As shown in Fig. 7, the maximum principal strain (εmax) on the upper BGA ball array is highly localized at the apex of each contact point. This strain concentration facilitates penetration of microscopic surface oxidation or contaminants on the gold-plated pads, thereby establishing stable, low-impedance electrical pathways. The simulation reveals that while local strain is sufficient for mechanical interlocking, overall stress remains well within the elastic limits of both the PCB substrate and the medical-grade encapsulation, ensuring that headstage components are not subjected to damaging mechanical deformation.
The stress distribution on the bottom pad array of the adapter PCB further validates the efficacy of the rotational-to-axial conversion strategy. Despite the manual nature of the tightening process, the threaded housing effectively translates torque into uniform pressure across the entire 25-mm footprint. This mechanical uniformity explains the high spatial consistency observed in the impedance heatmaps. By maintaining the conductive pillars under controlled axial compression, the system provides a robust, insertion-free interconnection that resists minor mechanical shocks and biological tissue shifts common in chronic neural recording applications.

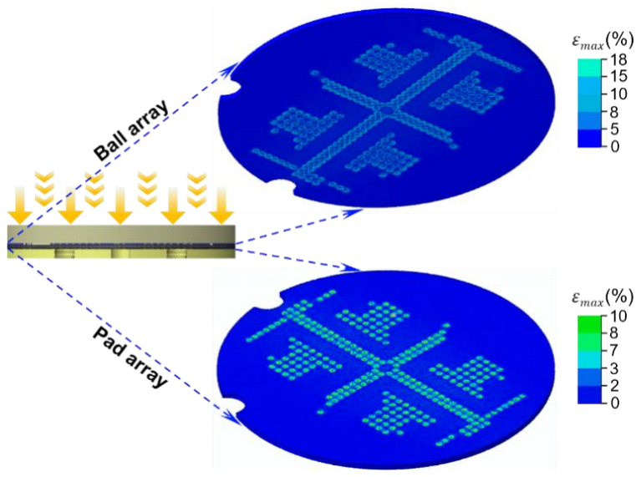
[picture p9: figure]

Fig. 7. FEA simulation of stress distribution at the upper and bottom contact interfaces. The simulation illustrates the localized maximum principal strain (εmax) across the (a) upper ball array and (b) bottom pad array during the 20% thickness compression phase. The uniform stress distribution validates the mechanical efficacy of the threaded housing in providing stable electrical interlocking across all 256 channels.

C. Operational Reliability and Reproducibility
A critical requirement for chronic neural interfaces is consistent performance regardless of operator or number of use cycles. To evaluate the human-factor reproducibility of our design, we conducted ten assembly trials performed by three independent users. The results, summarized in Fig. 8(a), reveal that connection yield remained high and consistent across all operators. This demonstrates that the manual threaded assembly effectively standardizes the axial pressure required for interlocking, decoupling electrical performance from the specific torque or technique applied by different users.
We investigated the long-term structural robustness and evaluated the material's compression set of the insertion-free interface through a mixed-mode longitudinal durability test. To simulate a chronic experimental lifecycle, the system underwent 100 mating trials distributed over five days (20 manual cycles per day). Between testing sessions, the assembly was continuously maintained in its fully mated, 20% statically compressed state. As illustrated in Fig. 8(b), the connection yield remained exceptionally stable, consistently exceeding 97%. This high repeatability is attributed to the solder-maskfree design of the adapter PCB and the compliant nature of the conductive elastomer, which together prevent permanent mechanical deformation of the contact pads even after extensive cycling.
To evaluate resilience under dynamic in vivo conditions, the assembled mini-pedestal underwent extended mechanical vibration testing (120 minutes) with acceleration profiles ranging from normal locomotion (8.0 m/s²) to extreme physical stress (22.9 m/s²). The system demonstrated excellent mechanical stability, maintaining a connection yield of 98.8% with negligible contact-impedance drift (Fig. S2). Furthermore, environmental sealing was verified through a

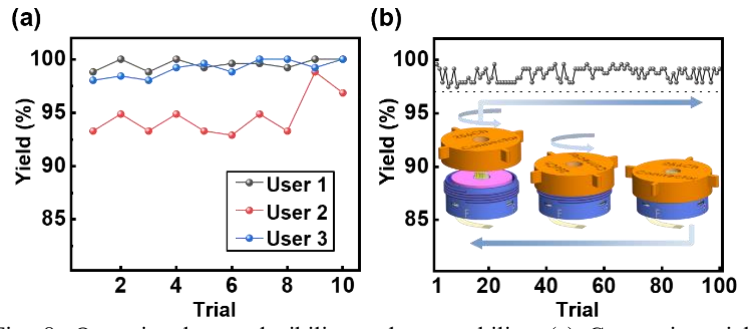
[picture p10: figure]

Fig. 8. Operational reproducibility and repeatability. (a) Connection yield across 10 assembly trials performed by three different users, demonstrating the robustness of the manual threaded interface against operator-induced variations. (b) Long-term stability analysis of the insertion-free interconnect, illustrating a maintained connection yield exceeding 97% across 100 consecutive mating trials.

prolonged exposure test, with the active thin-film probe fully immersed in a phosphate-buffered saline (PBS) bath for three days. Subsequent disassembly confirmed that the internal elastomeric interface and adapter PCB remained completely dry, demonstrating that the physical barrier provided by the threaded cap, foam washer, and potting compound effectively prevents fluid ingress and ensures operational stability in fluidic environments.

D. Thermal Stability and Heat Dissipation Analysis
Effective heat regulation within high-density neural interfaces remains critical for preventing localized tissue damage and ensuring the operational longevity of onboard electronics. Characterization of the 256-channel mini-pedestal connector's thermal behavior occurred during continuous high-speed data acquisition. As illustrated in Fig. 9, real-time temperature monitoring spanned a 4-hour period, simulating an intensive recording session under full-bandwidth SPI operation. To evaluate the system's thermal safety under peak operational load, we characterized its performance during continuous 256-channel data acquisition at a high sampling rate of 20 kHz. Real-time temperature monitoring in a PBS bath shows that the housing temperature increases gradually after data acquisition begins, reaching a steady-state value of approximately 30.5 °C after 35 minutes. The absolute operating temperature remains significantly lower than the typical biological baseline (37 °C). More importantly, the localized temperature elevation is maintained well within the stringent physiological safety limit of < 2 °C, ensuring that the
assembly's | modular | structural | architecture | effectively
dissipates the heat generated by the four RHD2164 chips [15]. By preventing heat accumulation during intensive recording sessions, the design ensures the long-term integrity of the electrode–tissue interface and the functional stability of the onboard electronics, fulfilling a critical requirement for high-density, chronic neural interfaces.
The infrared thermography inset in Fig. 9 provides detailed spatial mapping of the system's thermal dissipation characteristics at steady state. The results indicate that thermal energy is distributed uniformly across the headstage architecture and efficiently dissipated through the mini-pedestal

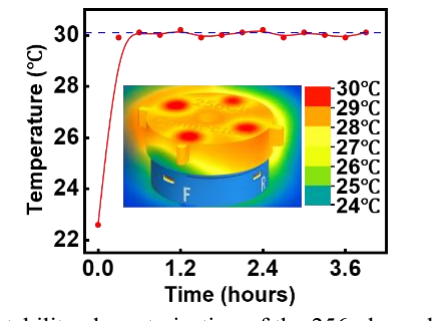
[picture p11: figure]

Fig. 9. Thermal stability characterization of the 256-channel connector during continuous operation. Real-time temperature monitoring conducted over a 4-hour duration under continuous full-bandwidth SPI data transmission at the 20 kHz maximum sampling rate. Inset: Infrared thermography illustrating the spatial temperature distribution across the headstage and mini-pedestal assembly at steady state, highlighting the efficient heat dissipation of the modular architecture.

housing. Efficient heat dissipation prevents the formation of localized thermal hotspots, safeguarding both the structural integrity of the polymer neural interface and the underlying biological tissue from adverse thermomechanical stress. Synergizing this thermal resilience with the mechanical stability of the insertion-free elastomeric interconnect guarantees sustained, high-fidelity signal acquisition over chronic implantation periods. The system maintains this high performance without relying on active cooling or restrictive duty cycles, facilitating continuous, high-bandwidth neural recording in freely behaving models.

E. Mechanical Durability
The long-term operational reliability of the 256-channel mini-pedestal connector is fundamentally governed by the mechanical resilience of the insertion-free elastomeric interface, particularly its capability to maintain structural integrity under repetitive mating-induced strain. To investigate the potential for material fatigue or permanent pillar deformation, we subjected the assembly to a 100-cycle durability protocol to simulate the extended lifecycle requirements of a modular neural headstage. This evaluation was complemented by high-resolution characterization of the
interposer's | surface | topography, | enabling | a | detailed
comparative analysis of the microstructures in both pre- and post-cycling states to validate long-term mechanical stability. As illustrated in Fig. 10(a), the pristine interposer exhibits a highly uniform surface morphology with well-defined conductive pillars. Following 100 consecutive mating and unmating cycles simulating intensive longitudinal use, microscopic inspection in Fig. 10(b) revealed that the interposer maintained its morphological integrity with negligible surface degradation or pillar deformation. Although minor dark residues are visible in the post-cycling micrographs, these were identified as trace metallic debris transferred from the headstage solder balls during repeated axial compression. This exogenous particulate matter did not compromise the elastomeric structure or the electrical conductivity of the interface, confirming the interposer's robust resistance to mechanical wear.

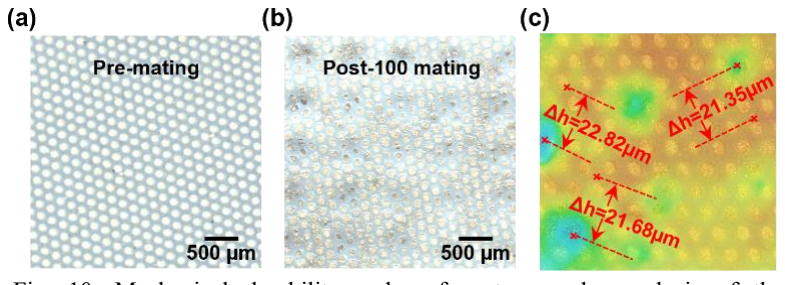
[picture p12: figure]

Fig. 10. Mechanical durability and surface topography analysis of the elastomeric interposer. (a) Optical micrograph showing the surface morphology of the interposer in its pre-mating (pristine) state. (b) Post-mating inspection after 100 consecutive mating cycles, demonstrating high structural integrity and minimal mechanical wear of the conductive pillars. (c) 3D surface topography mapping and corresponding recessed depth variations (Δh) across the array, validating the uniformity of the mechanical interface.

Quantitative 3D surface mapping Fig. 10(c) was utilized to assess the structural fidelity of the recessed interface, providing a high-resolution profile of the mechanical engagement across the array. Measurements yielded highly consistent recess depths with representative values of 22.82 μm, 21.35 μm, and 21.68 μm, demonstrating that the axial load is distributed with sub-micron precision across the 25-mm footprint. This minimal spatial variance confirms that the elastomeric interposer facilitates stable and uniform contact force, which is a prerequisite for ensuring low-impedance electrical coupling in high-density neural implants. Such mechanical robustness ensures that signal quality remains uncompromised over the device's operational lifespan, thereby fulfilling a critical engineering requirement for the chronic stability and signal integrity of high-bandwidth neural recording platforms.

F. In Vitro Electrical Characterization
Evaluation of the 256-channel interface's electrical integrity was conducted via comprehensive impedance spectroscopy utilizing a high-density polyimide-based ECoG array. This array architecture, which occupies a 400 × 400 μm² active area, features 60 × 60 μm² gold electrodes optimized for high-resolution neural recording.
Spatial electrode impedance mapping was conducted at 1 kHz to evaluate contact consistency across the large-scale insertion-free interface. As shown in the color-coded heatmap in Fig. 11(a), the system achieved exceptional uniformity across all 256 channels. Statistical analysis reveals that impedance magnitudes follow a tight Gaussian distribution with a mean of 397 kΩ and a standard deviation (SD) of 38.2 kΩ. Benchmarking of the acquisition fidelity involved a rigorous comparative characterization between the custom 256-channel headstage and a commercial Intan reference system. The resulting distributions, presented in Fig. 11(b), show the two platforms exhibit nearly identical profiles, with the Intanbenchmarked data yielding a mean impedance of 395 kΩ and an SD of 37.8 kΩ. This high degree of spectral overlap confirms that the elastomeric-based interconnect facilitates a reliable and
repeatable | electrical | coupling | that | is | functionally
indistinguishable from established industrial hardware, ensuring transparent signal transmission regardless of the hardware configuration.

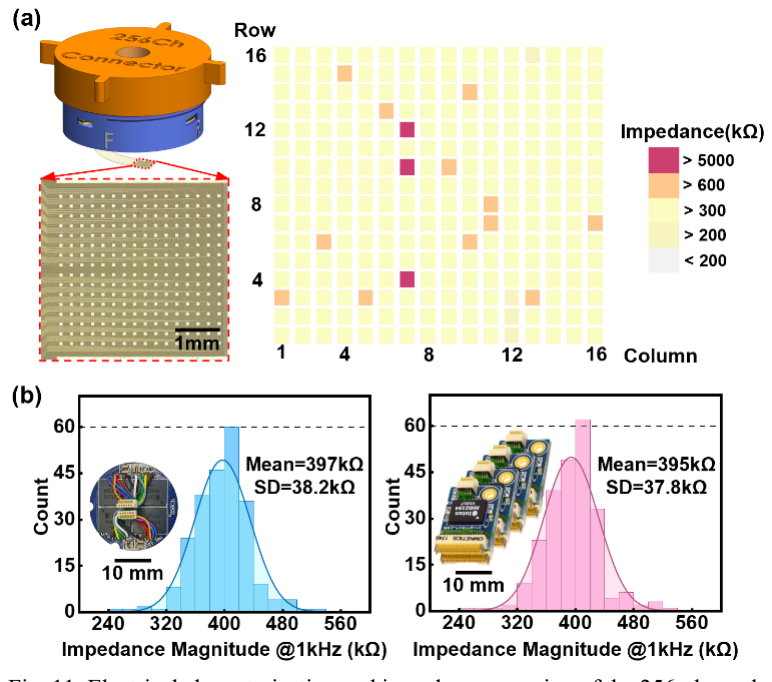
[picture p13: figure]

Fig. 11. Electrical characterization and impedance mapping of the 256-channel ECoG array. (a) Spatial electrode impedance mapping across the 400×400 μm² active area, featuring 60×60 μm² gold electrodes. The color-coded heatmap confirms exceptional contact uniformity and signal integrity across the entire 256-channel, insertion-free interface. (b) Comparative impedance distribution at 1 kHz benchmarked against a commercial Intan headstage to ensure hardware reproducibility. The experimental data are overlaid with Gaussian fit curves (solid lines), highlighting the tight impedance distribution. The high degree of spectral overlap confirms that the customized system achieves electrical coupling performance that is functionally equivalent to that of established commercial data-acquisition hardware.

G. Signal Fidelity and Noise Floor Characterization
To evaluate the dynamic signal acquisition performance of the 256-channel integrated system, we conducted in vitro validation using a 1-kHz sinusoidal input (approximately 20 mV peak-to-peak) in a PBS bath to emulate physiological loading conditions, as illustrated in Fig. 12(a).
The recorded waveforms across the entire 256 channels, shown in Fig. 12(b), exhibit clean, undistorted capture of the 1-kHz signal, with no observable phase offset or inter-channel amplitude variation. The ensemble average across all channels, represented by the thick blue trace, further confirms the exceptional spatial uniformity enabled by the insertion-free mini-pedestal architecture. It is noted that the absolute signal amplitude is attenuated relative to the applied excitation due to the impedance of the electrode–electrolyte interface and the AC-coupled front-end; however, this attenuation is global and consistent across channels and therefore does not affect the assessment of interconnect integrity or channel-to-channel uniformity.
To further quantify acquisition fidelity, we performed a power spectral density (PSD) analysis over a 10 Hz to 10 kHz bandwidth. As shown in Fig. 12(c), the spectral profile of our custom headstage (blue trace) is benchmarked against a commercial Intan headstage system (pink trace). Both systems exhibit a dominant 1-kHz signal peak corresponding to the input frequency, accompanied by well-defined higher-order

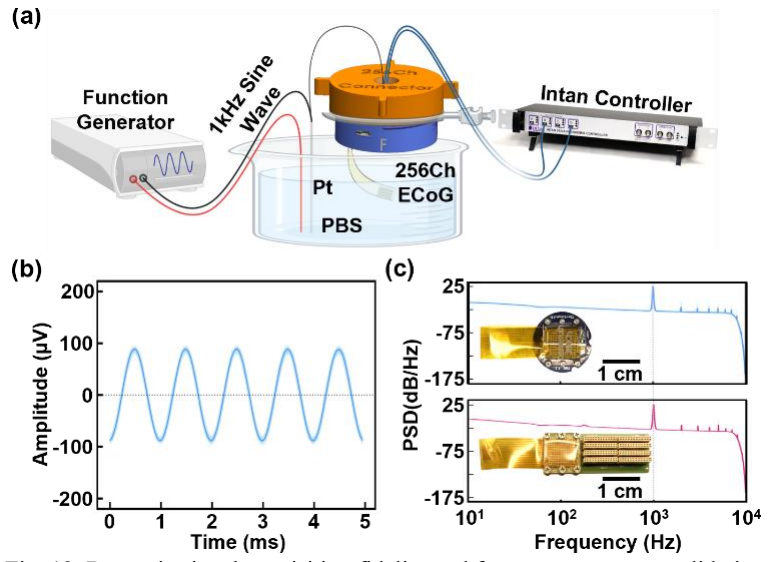
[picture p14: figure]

Fig. 12. Dynamic signal acquisition fidelity and frequency response validation via sine wave benchmarking. (a) Schematic of the in vitro test configuration in a PBS bath to emulate physiological loading conditions. (b) Simultaneously recorded 1 kHz sinusoidal waveforms from all 256 channels; the consistent overlay and the ensemble average (thick blue line) demonstrate high spatial uniformity and undistorted capture. (c) Comparative power spectral density (PSD) analysis between the customized system (blue) and the commercial Intan reference (pink). The identical signal peaks and overlapping noise floors across the full bandwidth (10 Hz – 10 kHz) validate that the proposed architecture preserves signal fidelity without introducing significant parasitic interference.

harmonics (2f, 3f, ...) that indicate excellent linearity in the signal chain.
Achieving a minimal intrinsic noise floor is a fundamental prerequisite for high-fidelity neural recording, particularly for accurately capturing low-amplitude signals such as local field potentials (LFPs) and single-unit action potentials. Evaluation of the electronic noise performance across the 256-channel mini-pedestal system involved shorting all input channels through a gold-film interface, a methodology that effectively isolates noise contributions from the custom PCB routing and connector assembly from the intrinsic noise of the active electronics [5], [16]. These characterizations were conducted across a frequency bandwidth of 0.1 Hz to 7.5 kHz, a range intentionally matched to the standard operational configuration and on-chip low-pass filter cutoff of the Intan RHD2164 controller.
The statistical distribution of the root-mean-square (RMS) noise across the full 256-channel array is presented in Fig. 13(a), revealing a tight Gaussian profile with a mean of 2.68 μV and a standard deviation (SD) of 0.46 μV. This empirical performance closely approximates the theoretical noise limit of 2.4 μV specified for the Intan RHD2164 chips [17]. Such precise alignment between the measured data and theoretical specifications demonstrates that the custom four-layer PCB stackup effectively suppresses EMI and mitigates digital-to-analog crosstalk by utilizing internal ground planes and strategic trace separation. This robust noise performance ensures that the system maintains high signal-to-noise ratios (SNR) even when deployed in electromagnetically active research or clinical settings.
Spectral analysis using PSD revealed the system's noise characteristics across the operational bandwidth, as illustrated

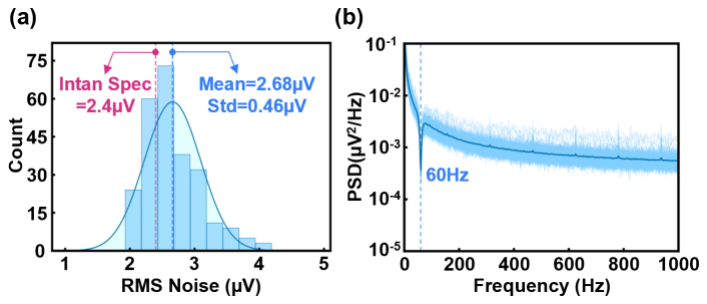
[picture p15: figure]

Fig. 13. System noise characterization with shorted input channels for sensitivity validation. (a) Statistical distribution of the RMS noise across all 256 channels; the experimental data (blue bars) are overlaid with a Gaussian fit (solid curve), yielding a mean value of 2.68 μV. This measured performance closely matches the theoretical amplifier limit, validating the effectiveness of the custom circuit design and shielding. (b) Power spectral density (PSD) analysis reveals a clean, broadband noise across the physiological frequency range, with the primary interference limited to the characteristic 60 Hz linefrequency peak.

in Fig. 13(b). Within the primary neural recording range of 10 Hz to 10 kHz, the architecture exhibits a notably clean, flat broadband noise floor that is largely consistent with the commercial Intan reference across the entire spectrum. This spectral flatness indicates that the system noise is dominated by the thermal noise of the input stage, suggesting that no significant 1/f noise or parasitic oscillations were introduced by the insertion-free interconnect. Additionally, the frequency response exhibits sharp attenuation at a cutoff frequency of 7.5 kHz, a characteristic that aligns precisely with the integrated low-pass filter settings of the RHD2164 amplifier. Environmental interference is primarily confined to a localized peak at 60 Hz and its subsequent harmonics, which represent standard power-line noise and are readily addressed through digital notch filtering during post-processing. The observed spectral consistency across the recording bandwidth demonstrates that the custom hardware maintains signal integrity comparable to that of established high-bandwidth neural recording systems. Validation of this insertion-free mini-pedestal architecture confirms its utility as a high-SNR solution that supports the data acquisition requirements of long-term electrophysiological research. By ensuring a high raw data fidelity, this interface provides the precision needed for accurate feature extraction and robust on-device processing, thereby supporting reliable performance in large-scale neural monitoring and real-time BCIs research paradigms. Furthermore, the high-density scalability and mechanical robustness of this platform suggest significant potential for translation into next-generation clinical neural interface [18].

V. DISCUSSION
A. Scalability Analysis: Pathway to 1024 Channels
The inherent scalability of anisotropic elastomeric technology represents a transformative shift from traditional rigid interconnects, offering a viable roadmap for the next generation of massive-scale neural interfaces. Evaluation of the spatial efficiency in Fig. 14(a) highlights a significant

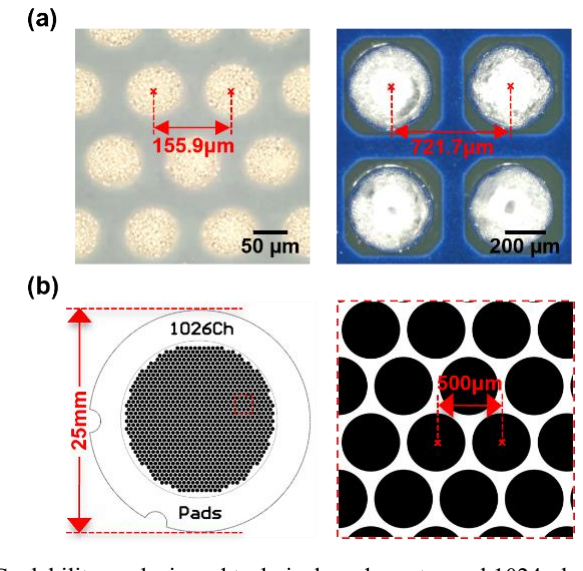
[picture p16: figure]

Fig. 14. Scalability analysis and technical roadmap toward 1024-channel high-density integration. (a) Comparative footprint analysis between the fine-pitch elastomeric conductive pillars and standard industrial solder balls, highlighting the superior packaging density afforded by the insertion-free interconnect strategy. (b) Conceptual pathway for scaling the mini-pedestal connector from 256 to 1024 channels within the same 25 mm diameter footprint for ultra-high-density polymer neural interfaces.

geometric advantage, where the fine-pitch conductive pillars (156 μm pitch) provide a 3.2× reduction in interconnect pitch compared to standard solder-ball arrays. This dimensional miniaturization is facilitated by eliminating bulky plastic housings and individual pin-and-socket architectures, allowing contact density to be governed primarily by PCB fabrication resolution and the elastomer's pillar frequency.
Analysis of the current mini-pedestal footprint suggests that the system can accommodate a 1024-channel high-density array within the same 25-mm-diameter envelope. This integration pathway, conceptualized in Fig. 14(b), relies on optimizing the four-layer PCB fan-out and refining the pillar arrangement to increase channel density without necessitating significant modifications to the existing mechanical compression housing. Such an expansion would involve migrating to a high-density interconnect (HDI) PCB process with finer trace/space design rules, effectively quadrupling the recording bandwidth while maintaining the lightweight, low-profile advantages of the current architecture.
B. Substrate Compatibility and Generalizability
A key advantage of the E-Link architecture is the mechanical decoupling of the mating interface from the functional substrate. While FEA indicates localized von Mises stress at the interposer during 20% axial compression, this load is entirely absorbed by the rigid adapter PCB and its supporting internal pedestal step. Because the thin-film probe is anchored to the underside of the adapter PCB, it remains outside the primary load path and experiences zero mating-induced strain. This structural isolation ensures that the system is not limited to stiff substrates like polyimide, but can safely accommodate ultralow-modulus materials, such as hydrogels or soft silicones, without risking trace deformation or plastic fracture.
The sandwich assembly employs a modular design to accommodate diverse substrate materials and thicknesses. The 1/32-inch transparent acrylic plate serves as a universal rigid backing, its thickness determined by the mini-pedestal's internal mechanical clearance. In contrast, the high-compliance silicone cushion serves as the primary tunable variable. For substrates significantly thicker or softer than standard polyimide (e.g.,
hydrogels), | the | cushion's | thickness | and | durometer—
controllable via spin-coating speed—are adjusted to match the
probe's | volumetric | profile | conformally. | This | tunable
compliance prevents localized 'pinching' or trace deformation, ensuring uniform contact pressure and reliable electrical engagement across varying material platforms.
C. Comparison with State-of-the-Art Performance Comparative assessment of the 256-channel mini-pedestal connector against established research and commercial headstages, as summarized in Table I, highlights significant performance breakthroughs in both channel density and mass. Quantitative analysis reveals that the proposed architecture achieves a substantial leap in channel count while maintaining a remarkably lightweight form factor of 2.8 g. This weight optimization proves particularly vital for longitudinal studies in small animal models, where minimizing head-mounted loads remains essential for preserving naturalistic behaviors and reducing localized mechanical strain at the implant site. Achieving such a high density-to-weight ratio ensures that the device remains a transparent interface for the subject, facilitating high-fidelity data acquisition without interfering with the biological phenomena under observation.
Superior scalability further distinguishes this design from commercial Intan-based headstages, which are frequently constrained to 64 or 128 channels within a comparable physical footprint. The mini-pedestal architecture establishes a validated framework for 256-channel acquisition while maintaining a
clear | developmental | trajectory | toward | 1024-channel
integration. This methodology enables a fourfold increase in recording bandwidth without necessitating an expansion of the volumetric footprint, effectively addressing the growing demand for massive-scale neural data acquisition. This roadmap toward thousands of channels is enabled by the inherent pitch scalability of the anisotropic elastomer, which allows significantly finer contact spacing than conventional mechanical pins.
Beyond the electrical and density advantages, the integrated mini-pedestal housing serves as a robust mechanical shield that significantly enhances the thin-film probe's physical durability. This structural enclosure provides a protective barrier that isolates the delicate, flexible traces from environmental contaminants and accidental mechanical impacts during the movements of freely behaving subjects [19]. By serving as a rigid, standardized strain-relief platform, the housing effectively redistributes mechanical loads away from the sensitive electrode-to-PCB transition zone, thereby ensuring the overall longevity of the neural interface throughout chronic recording. This dual-purpose design, providing both high-density interconnection and structural shielding, represents a critical advancement in the engineering of reliable, long-term neural implants.
D. Implications for Neuroscience and IoMT
This streamlined, rotate-and-play architecture addresses the practical challenges of deploying high-density interfaces in demanding environments. By replacing error-prone procedures with a reliable one-step connection, the system reduces surgical handling time and interface damage, allowing researchers to focus entirely on neural data acquisition.
A critical requirement for chronic neuroscience studies is reliable neural recording in freely moving animals [20]. To address this need, the mini-pedestal features a circular, low-profile form factor that ensures direct compatibility with both mechanical and motorized commutators while maintaining an overall stack height that preserves the intended experimental fit. Mechanical stability under torque and dynamic motion associated with animal behavior is achieved through a compact, thread-based rotational-to-axial compression mechanism. This design minimizes the risk of intermittent contact, signal dropout, or mechanical failure. Collectively, these design considerations support robust deployment of the 256-channel interface in freely moving neuroscience experiments, where cable management constraints or rigid connector architectures can otherwise limit recording duration or behavioral complexity. Standardizing high-density interfaces via this insertion-free methodology reduces technical barriers by eliminating the need for specialized micro-soldering and precision alignment. This empowers diverse laboratories to conduct large-scale recordings with high experimental reproducibility [21]. While currently targeting research applications, these core principles of mechanical compliance and scalable integration align directly with the operational requirements of Internet of
Medical | Things | (IoMT) | ecosystems, | where | device
maintainability and deployment scalability represent critical design considerations [22].
E. Limitations and Future Directions
Transitioning from 256 to 1024 channels, as conceptualized in Fig. 14, represents a significant engineering leap that necessitates a thorough re-evaluation of data throughput and thermal dissipation strategies. While the 256-channel configuration strictly maintains physiological thermal safety, the increased power density of a 1024-channel array will necessitate active power management. This may involve integrating ultra-low-power application-specific integrated circuits (ASICs), dynamic voltage scaling, and advanced thermal interface materials to mitigate localized heating within the compact housing.
Future work will also prioritize integrating high-bandwidth wireless modules for untethered monitoring, alongside on-device processing frameworks to manage massive data streams. Finally, chronic in-vivo validation in freely behaving subjects remains essential to ensure long-term biocompatibility and signal stability across diverse environments.

> IEEE JOURNAL ON FLEXIBLE ELECTRONICS, VOL. X, NO. X, MONTH YEAR <

TABLE I
COMPARISON OF COMMERCIAL AND RESEARCH HEADSTAGE

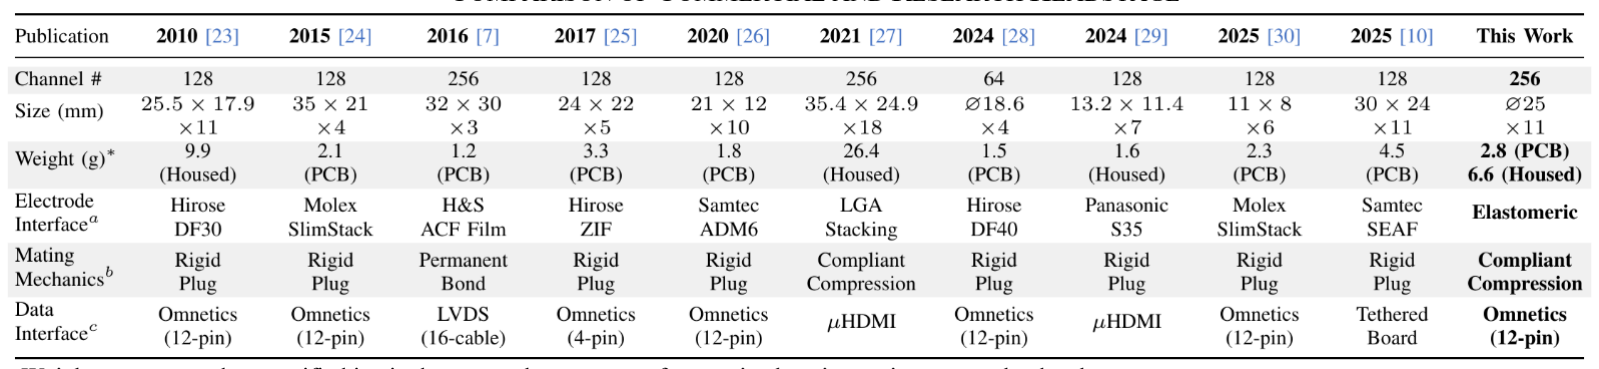
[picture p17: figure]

∗ Weights are reported as specified in cited sources; the presence of protective housing varies among the developers.
a Connection method used for the Electrode interface board (EIB) or adaptor board.
b Rigid Plug: requiring high insertion force and precise alignment; Permanent Bond: disposable headstage; Compliant Compression: low-force mating, selfaligned.

c
Interface to the data acquisition system.

VI. CONCLUSION
This work introduces a modular 256-channel mini-pedestal connector architecture that redefines the interconnection paradigm for chronic high-density neural interfaces. Utilization of an insertion-free elastomeric interposer, featuring alignment-tolerant conductive pillars and a mechanically compliant compression mechanism, facilitates a robust coupling solution that circumvents the insertion forces, alignment sensitivities, and mechanical fragilities inherent to traditional rigid pin-based systems. By transitioning away from permanent solder joints and rigid pins, the proposed design establishes a reliable electrical environment that prioritizes both structural longevity and ease of operation in complex surgical settings.
Empirical characterizations validate the system's high signal fidelity, reliable mechanical durability over repeated mating cycles, and strict adherence to physiological thermal safety limits. The integration of a lightweight form factor and a detachable architecture minimize the chronic head-mounted mass compared to conventional hardware, thereby mitigating behavioral artifacts and reducing localized tissue strain in freely behaving subjects. Implementation of this "rotate-and-play" insertion-free interface democratizes access to high-density neural recording by removing the requirement for specialized micro soldering expertise, effectively lowering the technical threshold for adoption in diverse neuroscience research environments. This user-centric approach ensures that the sophisticated capabilities of the system remain accessible for rapid deployment and cross-laboratory collaboration. Scalability analysis indicates a clear developmental roadmap toward 1024-channel integration within the existing 25-mm footprint, leveraging the superior pitch density of elastomeric conductive pillars (156 μm pitch) compared to traditional solder ball or pin-based arrays. This expansion capability, combined with the architecture's potential for wireless module integration, positions the mini-pedestal connector as a highly versatile platform for next-generation BCIs and the expanding IoMT. Such scalability ensures that the hardware can evolve in tandem with the increasing demands of massive-scale neural data acquisition.

The fundamental design principles established in this study offer a versatile framework for bridging the gap between soft sensors and rigid electronics. By utilizing mechanical flexibility for alignment, ensuring even pressure through threaded components, and enabling reusability via insertion-free contacts, this approach addresses the persistent challenges of high-density bioelectronic interfacing. As neural technologies continue to scale to thousands of channels, the development of robust, scalable packaging becomes just as vital as the innovation of the sensors themselves. These combined strategies provide a repeatable and reliable method for connecting delicate neural probes to standardized hardware, effectively solving the "soft-to-hard" integration problem that has long hindered the deployment of large-scale implants.

ACKNOWLEDGMENT
The authors gratefully acknowledge support from NIH
R01MH139342 | and | the | Dartmouth | PhD | Innovation
Fellowship.

REFERENCES

[1] P. Konrad, et al., “First-in-human experience performing high-resolution cortical mapping using a novel microelectrode array containing 1024 electrodes,” J Neural Eng, vol. 22, no. 2, Mar. 2025.
[2] Y. Qiang, et al., “Monolithic three-dimensional neural probes from deterministic rolling of soft electronics,” Nat Electron, vol. 8, no. 8, pp. 721-737, Aug. 2025.
[3] Y. Qi, et al., “Stabilized carbon coating on microelectrodes for scalable and interoperable neurotransmitter sensing,” Nat Commun, vol. 16, no. 1, pp. 3300, Apr. 2025.
[4] F. A. G. Mourao, et al., “A Fully Adapted Headstage With Custom Electrode Arrays Designed for Electrophysiological Experiments,” Front Neurosci, vol. 15, no. pp. 691788, 2021.
[5] T. Kaiju, M. Inoue, M. Hirata, and T. Suzuki, “Compact and low-power wireless headstage for electrocorticography recording of freely moving primates in a home cage,” Front Neurosci, vol. 19, no. pp. 1491844, 2025.
[6] X. Zhang, et al., “Compact packaging of high-throughput flexible neural multielectrode arrays for in vivo recording,” Sens Actuators A Phys, vol. 399, pp. 117347, Jan. 2026.
[7] G. Rios, E. V. Lubenov, D. Chi, M. L. Roukes, and A. G. Siapas, “Nanofabricated Neural Probes for Dense 3-D Recordings of Brain Activity,” Nano Lett, vol. 16, no. 11, pp. 6857-6862, Nov. 2016.
[8] S. Y. Park, et al., “A Miniaturized 256-Channel Neural Recording Interface With Area-Efficient Hybrid Integration of Flexible Probes and CMOS

> IEEE JOURNAL ON FLEXIBLE ELECTRONICS, VOL. X, NO. X, MONTH YEAR <

Integrated Circuits,” IEEE Trans Biomed Eng, vol. 69, no. 1, pp. 334-346,
Jan. 2022.
[9] L. Wang, et al., “High‐density implantable neural electrodes and chips for massive neural recordings,” Brain‐X, vol. 2, no. 2, 2024.
[10] E. K. Jacobs, M. Monge, A. Switalla, R. A. Frederick, and F. Deku, “Iris 128x: open-source 128 channel headstages for neural stimulation and recording,” J Neural Eng, vol. 22, no. 6, Nov. 2025.
[11] D. Yi, et al., “3D Printed Skull Cap and Benchtop Fabricated Microwire-Based Microelectrode Array for Custom Rat Brain Recordings,” Bioengineering (Basel), vol. 9, no. 10, Oct. 2022.
[12] J. Ryu, et al., “Multifunctional Nanomesh Enables Cellular-Resolution, Elastic Neuroelectronics,” Adv Mater, vol. 36, no. 36, pp. 141, Sep. 2024.
[13] T. B. Yasar, et al., “Months-long tracking of neuronal ensembles spanning multiple brain areas with Ultra-Flexible Tentacle Electrodes,” Nat Commun, vol. 15, no. 1, pp. 4822, Jun. 2024.
[14] Q. Li, Z. Zhang, M. Shi, and X. Tao, “Multi-channel Neural Signal Recording System for an Implantable Brain-Computer Interface,” Annu Int Conf IEEE Eng Med Biol Soc, vol. 2024, no. pp. 1-5, Jul. 2024.
[15] M. Rizk, et al., “A fully implantable 96-channel neural data acquisition system,” J Neural Eng, vol. 6, no. 2, pp. 026002, Apr. 2009.
[16] K. Barth, C. Schmitz, T. Jochum, and J. Viventi, “Intan Technologies integrated circuits can produce analog-to-digital conversion artifacts that affect neural signal acquisition,” J Neural Eng, vol. 21, no. 4, Jul. 2024.
[17] Intan Technologies, LLC. (2021, Dec. 1). RHD2164 Chip. [Datasheet]. Available: https://intantech.com/files/Intan_RHD2164_datasheet.pdf
[18] C. H. Chiang, et al., “Flexible, high-resolution thin-film electrodes for human and animal neural research,” J Neural Eng, vol. 18, no. 4, Jun. 2021.
[19] M. Voroslakos, P. C. Petersen, B. Voroslakos, and G. Buzsaki, “Metal microdrive and head cap system for silicon probe recovery in freely moving rodent,” Elife, vol. 10, May. 2021.
[20] J. P. Newman, et al., “ONIX: a unified open-source platform for multimodal neural recording and perturbation during naturalistic behavior,” Nat Methods, vol. 22, no. 1, pp. 187-192, Jan. 2025.
[21] J. H. Siegle, G. J. Hale, J. P. Newman, and J. Voigts, “Neural ensemble communities: open-source approaches to hardware for large-scale electrophysiology,” Curr Opin Neurobiol, vol. 32, no. pp. 53-9, Jun. 2015.
[22] J. Y. Park, et al., “Lessons Learned and Challenges Ahead in the Translation of Implantable Microscale Sensors and Actuators,” Annu Rev Biomed Eng, vol. 27, no. 1, pp. 211-233, May. 2025.
[23] T.-D. Technologies. (2024). ZC128: ZIF-Clip Analog Headstages Technical Specifications. [Online]. Available: https://tdt.com/docs/hardware/zif-clip-analog-headstages/#zif-clip-zcheadstages-technical-specifications (Accessed: Jan. 29, 2026).
[24] Intan Technologies, LLC. (2025). RHD2000_128-Channel Headstage. [Datasheet]. Available:
https://intantech.com/files/Intan_RHD2000_128_channel_headstage.pdf
[25] Neuropixels. (2024). 128Ch NRIC Datasheet. [Online]. Available: https://1d1204a4-e092-4bd5-ab7d-6d350a74299f.filesusr.com/ugd/328966_c59e77054175456cb0c3ef82b3 2219c1.pdf (Accessed: Jan. 29, 2026).
[26] Plexon. (2020.). Digital Headstage Technical Guide. [Online]. Available: https://plexon.com/wp-content/uploads/2020/01/Digital-Headstage-Technical-Guide.pdf (Accessed: Jan. 29, 2026)
[27] Blackrock Neurotech. (2024). CerePlex E256 Digital Headstage. [Online]. Available: https://blackrockneurotech.com/products/cereplexe256/ (Accessed: Jan. 29, 2026).
[28] Open Ephys. (2024). Headstage-64: ONIX Hardware Guide. [Online]. Available: https://open-ephys.github.io/onixdocs/Hardware%20Guide/Headstages/headstage-64/index.html (Accessed: Jan. 26, 2026).
[29] Kontex. (2024). X6R: 128-Channel Digital Headstage with HDMI Interface. [Online]. Available: https://docs.kontex.io/Headstage/X6R/X6R128_HDMI/ (Accessed: Jan. 26, 2026).
[30] Cambridge Neurotech. (2024). Mini-amp-128 Digital Headstage. [Online]. Available: https://www.cambridgeneurotech.com/headstages (Accessed: Jan. 29, 2026).

Tianyu Bai received the B.S. degree in electrical engineering and mathematics from the University of Missouri, Columbia, MO, USA, in 2019. He is currently pursuing a Ph.D. degree in engineering science at Dartmouth College, Hanover, NH, USA.
His current research focuses on the
intersection | of microelectronics | and
neuroscience, | specifically | in | miniaturized | hardware
implementation, insertion-free interconnect technologies, and the system integration of high-bandwidth neural recording platforms.

Gen Li received the B.E. degree in
Thermal | and | Energy | from | Tongji
University, Shanghai, China, in 2016, the M.S. degree and the Ph.D. degree in
Mechanical | Engineering | from | the
University of Illinois at Chicago, Chicago, US, in 2017 and 2021.
He is currently a research scientist at Dartmouth College, Hanover, NH, USA. His current research interests include mechanics in neural engineering and the development of next-generation brainmachine interfaces, with a particular focus on polymer-based chronic brain implants.

Yongli Qi received the B.E. degree in Polymer Materials and Engineering from Sun Yat-sen University, Guangdong, China, in 2013, and the Ph.D. degree in Chemistry and Physics of Polymers from Fudan University, Shanghai, China, in 2019.
She is currently a research scientist at Dartmouth College, Hanover, NH, USA. Her current research interests include the development of multifunctional neuroelectronic platforms for neural probing and modulation, with a particular emphasis on decoding brain chemistry.

Hui Fang received the B.S. degree in materials science and engineering from Tsinghua University, Beijing, China, in 2009, and the Ph.D. degree in materials
science | and | engineering | from | the
University of California, Berkeley, CA, USA, in 2014.
He is currently an Associate Professor at Dartmouth College, Hanover, NH, USA, where he also serves as the Faculty Director of the Micro and Nano Fabrication Facility. His research focuses on multifunctional materials and devices for large-scale soft microsystem development.
Dr. Fang has received the National Science Foundation CAREER Award and the Thayer Distinguished Research Award for Faculty for his work in neural implant technology.

> IEEE JOURNAL ON FLEXIBLE ELECTRONICS, VOL. X, NO. X, MONTH YEAR <

SUPPLEMENTARY MATERIAL

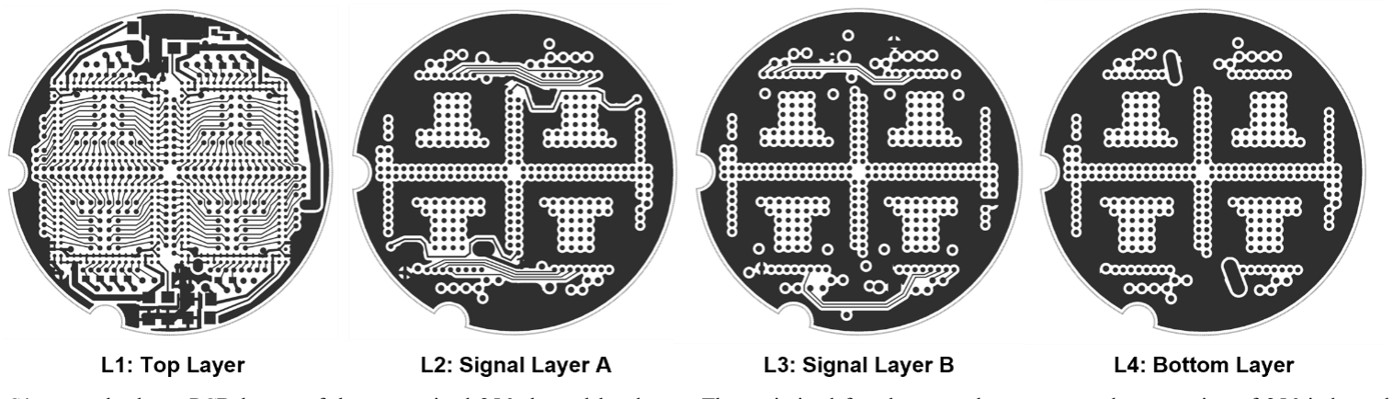
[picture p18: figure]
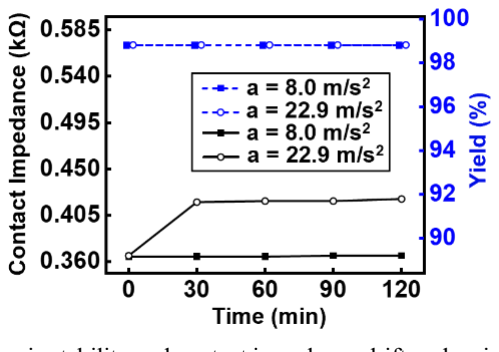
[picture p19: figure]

Fig. S2. Dynamic stability and contact impedance drift under simulated motion and micro-vibration. The system demonstrated robust electrical stability over a 120-minute test. Impedance drift was minimal under both 8.0 m/s² (simulating standard dynamic motion) and 22.9 m/s² (simulating extreme micro-vibration) acceleration conditions, and the overall connection yield remained unchanged at 98.8% throughout both testing conditions.

Fig. S1. Layer-by-layer PCB layout of the customized 256-channel headstage. The optimized four-layer stackup manages dense routing of 256 independent channels while ensuring signal integrity. L1 (top) hosts the four symmetrically arranged RHD2164 analog front-end ICs and miniaturized passives. L2 and L3 bury critical high-speed differential SPI communication lines and power (VDD) distribution within grounded copper pours to provide electromagnetic shielding and mitigate digital-to-analog crosstalk. L4 (bottom) serves as a continuous ground plane to provide stable signal return paths and accommodates the high-density BGA footprint for the insertion-free elastomeric interface.

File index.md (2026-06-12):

---
layout: default
title: E-Link Home
---

<link rel="preconnect" href="https://fonts.googleapis.com">
<link rel="preconnect" href="https://fonts.gstatic.com" crossorigin>
<link rel="stylesheet" href="https://fonts.googleapis.com/css2?family=Inter:wght@400;600;800&family=JetBrains+Mono:wght@400;700&display=swap">

<style>
/* 1. 外层静态阴影容器 */
.header-sync-pulse {
  margin: 0;
  display: inline-block;
  border-radius: 4px;
  margin-bottom: 5px;
  filter: drop-shadow(0 0 8px rgba(96, 165, 250, 0.3)); 
}

/* 2. 【英文版专属】图片遮罩与光束扫过 */
.logo-mask-container {
  position: relative; 
  /* 加上 max-content 锁死宽度 */
  display: inline-block; 
  width: max-content; 
  max-width: 100%;
}

.logo-mask-container::after {
  content: "";
  position: absolute;
  inset: 0; /* 覆盖底层图片 */
  
  /* 把遮罩仅应用于光束层！底图绝对安全 */
  -webkit-mask-image: var(--logo-url); 
  mask-image: var(--logo-url);
  -webkit-mask-size: contain;
  -webkit-mask-position: center;
  -webkit-mask-repeat: no-repeat;
  
  /* 使用带角度的渐变代替 transform skewX，手机端硬件加速更流畅 */
  background: linear-gradient(
    105deg, 
    transparent 0%, 
    transparent 20%,
    rgba(96, 165, 250, 0.4) 35%,   
    rgba(167, 139, 250, 0.95) 50%, 
    rgba(167, 139, 250, 0.95) 60%, 
    rgba(96, 165, 250, 0.4) 75%,   
    transparent 90%,
    transparent 100%
  );
  background-size: 250% 100%;
  background-repeat: no-repeat;
  mix-blend-mode: screen;
  pointer-events: none;
  animation: safe-sweep-anim 3s linear infinite;
}

/* Logo 扫光：英文 .logo-mask-container::after 与中文 .logo-mask-zh::after 共用 */
@keyframes safe-sweep-anim {
  0%   { background-position: 200% 0; }
  75%  { background-position: -100% 0; }
  100% { background-position: -100% 0; }
}

/* 3. SVG 图标与纯文本双层背景扫光 */
.bi-color-title-sweep {
  background: 
    linear-gradient(105deg, transparent 0%, rgba(255, 255, 255, 0.5) 25%, rgba(255, 255, 255, 1) 50%, rgba(255, 255, 255, 0.5) 75%, transparent 100%),
    linear-gradient(90deg, #60a5fa 0%, #a78bfa 55%, #f472b6 100%);
  background-size: 250% auto, 100% auto; 
  background-repeat: no-repeat;
  -webkit-background-clip: text; 
  background-clip: text;
  -webkit-text-fill-color: transparent; 
  color: transparent;
  animation: text-searchlight 3s linear infinite;
}

@keyframes text-searchlight {
  0%  { background-position: -50% center, 0 center; }
  70% { background-position: 150% center, 0 center; }
  100% { background-position: 150% center, 0 center; }
}

/* 4. 通用副标题样式 */
.sub-title {
  background: linear-gradient(90deg, #60a5fa 0%, #818cf8 50%, #a78bfa 100%);
  -webkit-background-clip: text; -webkit-text-fill-color: transparent;
  font-family: 'Inter', system-ui, sans-serif; font-weight: 700;
  font-size: 1.5em; letter-spacing: -0.5px; text-align: center;
  margin-top: 0; line-height: 1.4; max-width: 90%; margin-left: auto; margin-right: auto;
}

/* 5. 新增：专门控制中文“易链”两个字的大小，使其与右侧图片高度协调 */
.zh-text-logo {
  font-size: 70px;
  font-weight: 800;
  letter-spacing: 4px;
  font-family: 'Inter', 'Noto Sans SC', sans-serif;
  line-height: 1;
}

/* 🚀 新增：英文版 Logo 电脑端基础大小控制 */
.main-logo {
  display: block;
  height: 120px !important;        
  width: auto !important;      
  max-width: 100% !important;     
  object-fit: contain;
  margin-left: auto;
  margin-right: auto;
} 

/* 👇 手机端优化适配 👇 */
@media (max-width: 768px) {
  .main-logo { height: 66px !important; } 
  .sub-title { font-size: 1.2em !important; padding: 0 10px !important; white-space: normal !important; }
  .mobile-br::before { content: "\A"; white-space: pre; }
} 
</style>

<div class="lang-en" markdown="1">

<div class="github-only">
  <p align="center">
    <a href="https://tianyu-bai.github.io/E-Link">
      🌐 Click here to view the interactive website
    </a>
  </p>
</div>

<style>
/* ===================== Section Jump Nav (glass pills) ===================== */
.elink-jump-nav {
  display: flex; flex-wrap: wrap; justify-content: center;
  gap: 8px; max-width: 900px; margin: 0 auto 16px; padding: 0 5px;
  box-sizing: border-box;
}
.ej-pill {
  position: relative; overflow: hidden;
  display: inline-flex; align-items: center; gap: 6px;
  padding: 7px 14px; border-radius: 22px;
  font-family: 'JetBrains Mono', monospace; font-size: 11.5px; font-weight: 700;
  letter-spacing: .4px; text-decoration: none; white-space: nowrap;
  color: #cbd5e1;
  background: rgba(15, 23, 42, 0.55);
  border: 1px solid rgba(59,130,246,.25);
  backdrop-filter: blur(8px); -webkit-backdrop-filter: blur(8px);
  box-shadow: inset 0 0 12px rgba(59,130,246,.06), 0 2px 8px rgba(0,0,0,.2);
  transition: transform .28s cubic-bezier(.25,.8,.25,1), color .28s ease,
              border-color .28s ease, box-shadow .28s ease, background .28s ease;
}
.ej-pill::before {
  content: ''; position: absolute; inset: 0; border-radius: inherit; pointer-events: none;
  background: linear-gradient(180deg, rgba(255,255,255,.07), transparent 55%);
}
.ej-pill:hover,
.ej-pill:focus-visible {
  color: #fff; outline: none;
  border-color: rgba(96,165,250,.6);
  background: linear-gradient(135deg, rgba(59,130,246,.28), rgba(167,139,250,.18));
  transform: translateY(-3px);
  box-shadow: 0 8px 22px rgba(59,130,246,.3), inset 0 0 14px rgba(96,165,250,.15);
}
.ej-pill:focus-visible { box-shadow: 0 0 0 2px rgba(96,165,250,.65), 0 8px 22px rgba(59,130,246,.3); }
.ej-pill:active { transform: translateY(-1px) scale(.97); }
.ej-pill .ej-ico { font-size: 13px; line-height: 1; filter: drop-shadow(0 0 5px rgba(96,165,250,.5)); }

/* Light mode */
body.light-mode .ej-pill {
  background: rgba(255,255,255,.7); color: #475569;
  border-color: rgba(59,130,246,.25);
  box-shadow: inset 0 0 12px rgba(59,130,246,.04), 0 2px 8px rgba(148,163,184,.15);
}
body.light-mode .ej-pill:hover,
body.light-mode .ej-pill:focus-visible {
  color: #1e40af; border-color: #60a5fa;
  background: linear-gradient(135deg, rgba(59,130,246,.12), rgba(167,139,250,.1));
  box-shadow: 0 8px 22px rgba(148,163,184,.25);
}

@media (max-width: 600px) {
  .elink-jump-nav { gap: 6px; }
  .ej-pill {
    padding: 6px 12px; font-size: 11px;
    backdrop-filter: none; -webkit-backdrop-filter: none;
    background: rgba(15, 23, 42, 0.82);
  }
  body.light-mode .ej-pill { background: rgba(255,255,255,.92); }
}

@media (prefers-reduced-motion: reduce) {
  .ej-pill { transition: none; }
  .ej-pill:hover, .ej-pill:focus-visible { transform: none; }
}

[id^="en-"], [id^="cn-"] { scroll-margin-top: 30px; }
</style>

<div class="elink-jump-nav">
  <a class="ej-pill" href="#en-overview"><span class="ej-ico">📖</span>Overview</a>
  <a class="ej-pill" href="#en-features"><span class="ej-ico">✨</span>Features</a>
  <a class="ej-pill" href="#en-specs"><span class="ej-ico">📊</span>Specs</a>
  <a class="ej-pill" href="#en-components"><span class="ej-ico">🧩</span>Components</a>
  <a class="ej-pill" href="#en-bom"><span class="ej-ico">🛠</span>BOM</a>
  <a class="ej-pill" href="#en-downloads"><span class="ej-ico">🔗</span>Downloads</a>
</div>

<div align="center" style="margin-top: 26px; margin-bottom: 5px;">
  <h1 class="header-sync-pulse">
    <span class="logo-mask-container" style="--logo-url: url('{{ "/Images/ELink Logo color.png" | relative_url }}')">
      E-Link Logo color
    </span>
  </h1>
</div>

<h2 class="sub-title" data-aos="fade-up" data-aos-delay="200">
  An Open-Source, Elastomer Interconnection-based <br class="mobile-only-br"> Connector for Flexible Neural Interfaces
</h2>

<div align="center" style="margin-top: 15px;">
   
    
    
    
     
 </div>
  
<div align="center">
 <br>
 E-Link(256) Exploded View
 <p style="margin-top: 5px; font-size: 0.95em; color: #3b82f6;">
   <b>Mating Dynamics (left) and Structural Breakdown (right) of the E-Link(256) </b>
 </p>
</div>

<style>
/* 🚀 终极防溢出护盾：彻底锁死横向滚动条 */
html { overflow-x: hidden; width: 100%; -webkit-text-size-adjust: 100%; }
body { overflow-x: hidden; width: 100%; position: relative; margin: 0; padding: 0; font-family: 'Inter', -apple-system, BlinkMacSystemFont, "Segoe UI", sans-serif; }
*, *::before, *::after { box-sizing: border-box; }

/* 占位由父容器负责 */
.gif-placeholder { width: 100%; max-width: 500px; min-height: 280px; margin: 0 auto; display: flex; align-items: center; justify-content: center; background: rgba(15, 23, 42, 0.15); border-radius: 8px; overflow: hidden; }
.gif-placeholder.narrow { max-width: 460px; }
.lazy-gif { width: 100%; height: auto; display: block; opacity: 0; transition: opacity 0.4s ease; border-radius: 6px; }
.lazy-gif.is-loaded { opacity: 1; }
  
/* ===================== 1. 核心设备感知与显隐逻辑 ===================== */
.pc-tip, .mobile-tip, .pc-only, .mobile-only { display: none !important; }
@media (pointer: fine) { .pc-tip, .pc-only { display: inline !important; } }
@media (pointer: coarse) { .mobile-tip, .mobile-only { display: inline !important; } }

/* ========================================= 2. 复杂时间轴与动作动画 ========================================= */
@keyframes timeline-drag-container {
  0%             { opacity: 0; z-index: 10; }
  0.5%, 5.75%    { opacity: 1; z-index: 10; }
  6.25%, 12%     { opacity: 0; z-index: -1; }
  12.5%, 18.25%  { opacity: 1; z-index: 10; }
  18.75%, 55.75% { opacity: 0; z-index: -1; }
  56.25%, 62%    { opacity: 1; z-index: 10; }
  62.5%, 100%    { opacity: 0; z-index: -1; }
}

@keyframes timeline-zoom-container {
  0%, 5.75%      { opacity: 0; z-index: -1; }
  6.25%, 12%     { opacity: 1; z-index: 10; }
  12.5%, 18.25%  { opacity: 0; z-index: -1; }
  18.75%, 24.5%  { opacity: 1; z-index: 10; }
  25%, 62%       { opacity: 0; z-index: -1; }
  62.5%, 68.25%  { opacity: 1; z-index: 10; }
  68.75%, 100%   { opacity: 0; z-index: -1; }
}

@keyframes move-drag-hand {
  0% { transform: translateX(-40px) rotate(-15deg); opacity: 0; }
  20% { opacity: 1; }
  80% { opacity: 1; }
  100% { transform: translateX(40px) rotate(5deg); opacity: 0; }
}

@keyframes move-zoom-left-diagonal {
  0% { transform: translate(-30px, 15px); opacity: 0; } 
  20% { opacity: 1; }
  80% { opacity: 1; }
  100% { transform: translate(-90px, 65px); opacity: 0; } 
}

@keyframes move-zoom-right-diagonal {
  0% { transform: translate(30px, -15px); opacity: 0; } 
  20% { opacity: 1; }
  80% { opacity: 1; }
  100% { transform: translate(90px, -65px); opacity: 0; } 
}

/* ========================================= 3. 容器与图标样式 ========================================= */
.gesture-overlay { position: absolute; top: 50%; left: 50%; transform: translate(-50%, -50%); pointer-events: none; text-align: center; width: 220px; height: 150px; display: flex; flex-direction: column; justify-content: center; align-items: center; }
.mode-drag { animation: timeline-drag-container 48s infinite; }
.mode-zoom { animation: timeline-zoom-container 48s infinite; }
.icon-box { position: relative; height: 80px; width: 100%; margin-bottom: 5px; }

.hand-icon { font-size: 50px; position: absolute; top: 20px; left: 50%; text-shadow: 2px 4px 0px rgba(0,0,0,0.8), 0 0 10px rgba(0,0,0,0.5); will-change: transform, opacity; }
.mode-drag .hand-icon { margin-left: -25px; animation: move-drag-hand 1.5s infinite ease-in-out; }
.mode-zoom .hand-icon { margin-left: -25px; top: 15px; }
.mode-zoom .hand-left { animation: move-zoom-left-diagonal 1.5s infinite ease-in-out; }
.mode-zoom .hand-right { animation: move-zoom-right-diagonal 1.5s infinite ease-in-out; }

.gesture-text { color: white; font-family: sans-serif; font-weight: bold; font-size: 16px; text-shadow: 0 2px 4px black; background: rgba(0,0,0,0.4); padding: 4px 12px; border-radius: 12px; white-space: nowrap; }

/* ===================== 4. HUD 与交互反馈 ===================== */
.gesture-hud { position: absolute; top: 12px; left: 50%; transform: translateX(-50%); display: flex; align-items: center; gap: 25px; font-size: 13px; font-family: system-ui, sans-serif; color: rgba(255, 255, 255, 0.65); background: rgba(15, 23, 42, 0.45); border: 1px solid rgba(59,130,246,0.25); padding: 6px 10px; border-radius: 20px; white-space: nowrap; backdrop-filter: blur(6px); -webkit-backdrop-filter: blur(6px); pointer-events: none; transition: opacity 0.4s ease; z-index: 5; }
.gesture-hidden { opacity: 0 !important; visibility: hidden !important; pointer-events: none !important; animation: none !important; }
.gesture-hidden * { animation: none !important; }
.gesture-overlay, .gesture-overlay * { animation-play-state: paused !important; }
.gesture-overlay.gesture-active, .gesture-overlay.gesture-active * { animation-play-state: running !important; }

.reset-btn { position: absolute; bottom: 16px; left: 16px; z-index: 10; background: rgba(15, 23, 42, 0.6); border: 1px solid rgba(59, 130, 246, 0.3); color: rgba(255, 255, 255, 0.8); border-radius: 8px; padding: 6px 12px; font-family: system-ui, sans-serif; font-size: 12px; cursor: pointer; backdrop-filter: blur(4px); -webkit-backdrop-filter: blur(4px); transition: all 0.3s ease; display: flex; align-items: center; gap: 6px; }
.reset-btn:hover { background: rgba(59, 130, 246, 0.4); color: #fff; transform: scale(1.05); }

kbd { background-color: rgba(255, 255, 255, 0.1); border-radius: 4px; border: 1px solid rgba(255, 255, 255, 0.3); box-shadow: 0 1px 1px rgba(0,0,0,0.2); font-family: inherit; font-size: 0.9em; font-weight: 600; padding: 1px 4px; margin: 0 2px; color: #60a5fa; }

/* ===================== 5. 模型全局基础样式 ===================== */
.custom-model-viewer { width: 100%; max-width: 100%; box-sizing: border-box; height: 460px; background: rgba(15, 23, 42, 0.45); backdrop-filter: blur(12px); -webkit-backdrop-filter: blur(12px); border-radius: 16px; border: 1px solid rgba(59,130,246,0.3); box-shadow: 0 15px 35px rgba(0, 0, 0, 0.5), inset 0 0 15px rgba(255,255,255,0.05); outline: none; overflow: hidden; transform: translateZ(0); backface-visibility: hidden; touch-action: none; isolation: isolate; }
.custom-model-viewer:focus, .custom-model-viewer:active, .custom-model-viewer:focus-visible { outline: none !important; box-shadow: none !important; border: 1px solid rgba(59,130,246,0.3) !important; }
model-viewer, model-viewer:focus-within, model-viewer:focus-visible { outline: none !important; -webkit-tap-highlight-color: transparent; }
.model-block { max-width: 100% !important; margin-top: 5px !important;  margin-bottom: 15px !important; }
model-viewer::part(interaction-prompt), model-viewer::part(default-progress-bar) { display: none !important; }
model-viewer > [slot="poster"] { width: 100%; height: 100%; position: absolute; top: 0; left: 0; }

.model-watermark-text { position: absolute; bottom: 12px; right: 16px; font-family: 'JetBrains Mono', monospace; font-size: 10px; color: rgba(255, 255, 255, 0.25); pointer-events: none; z-index: 5; font-weight: 400; }
@keyframes text-blink { 0%, 100% { opacity: 1; } 50% { opacity: 0.3; } }
.gesture-hud span + span { position: relative; padding-left: 5px; }
.gesture-hud span + span::before { content: ""; position: absolute; left: -12px; top: 20%; height: 60%; width: 1px; background: rgba(255, 255, 255, 0.2); }

/* ===================== 🚀 浅色模式专属：3D 模型 UI 界面适配 ===================== */
body.light-mode .gesture-hud { color: #1e293b !important; background: rgba(255, 255, 255, 0.7) !important; border-color: rgba(59, 130, 246, 0.3) !important; box-shadow: 0 4px 12px rgba(148, 163, 184, 0.2) !important; }
body.light-mode .gesture-hud span + span::before { background: rgba(0, 0, 0, 0.15) !important; }
body.light-mode .gesture-text { color: #1e293b !important; text-shadow: none !important; background: rgba(255, 255, 255, 0.85) !important; border: 1px solid rgba(59, 130, 246, 0.2) !important; box-shadow: 0 4px 15px rgba(148, 163, 184, 0.2) !important; }
body.light-mode .reset-btn { background: rgba(255, 255, 255, 0.8) !important; color: #334155 !important; border-color: rgba(148, 163, 184, 0.4) !important; box-shadow: 0 2px 8px rgba(148, 163, 184, 0.15) !important; }
body.light-mode .reset-btn:hover { background: #ffffff !important; color: #2563eb !important; border-color: #60a5fa !important; }
body.light-mode .model-block [slot="poster"] { background: radial-gradient(circle at center, #f8fafc 0%, #e2e8f0 100%) !important; }
body.light-mode .model-block [slot="poster"] > div:nth-child(1) { background-image: linear-gradient(rgba(59, 130, 246, 0.15) 1px, transparent 1px), linear-gradient(90deg, rgba(59, 130, 246, 0.15) 1px, transparent 1px) !important; }
body.light-mode .model-block [slot="poster"] p:first-of-type { color: #1e40af !important; text-shadow: 0 0 10px rgba(59, 130, 246, 0.3) !important; }
body.light-mode .model-block [slot="poster"] .click-to-load-glow { color: #64748b !important; }
body.light-mode .model-block [slot="poster"] .click-to-load-glow:hover { text-shadow: 0 0 10px rgba(59, 130, 246, 0.5) !important; }
body.light-mode .model-watermark-text { color: rgba(71, 85, 105, 0.6) !important; }
  
/* ===================== E-Link 动态仪表盘样式 ===================== */
.nav-badges img, .github-only img, a img { transform: translateZ(0); backface-visibility: hidden; -webkit-font-smoothing: antialiased; }
.elink-dynamic-dashboard { width: 100%;  max-width: 760px;  margin: 20px auto;  padding: 0 5px; box-sizing: border-box; }
.metrics-grid { display: flex;  justify-content: space-between;  align-items: center;  flex-wrap: nowrap; gap: 12px;  width: 100%; box-sizing: border-box; }
.metric-card.glass-panel { flex: 1 1 0; min-width: 0; background: rgba(15, 23, 42, 0.6); border: 1px solid rgba(59, 130, 246, 0.3); border-radius: 12px; padding: 15px 5px; box-sizing: border-box; box-shadow: 0 8px 32px 0 rgba(0, 0, 0, 0.3); backdrop-filter: blur(8px); -webkit-backdrop-filter: blur(8px); transition: transform 0.3s ease; text-align: center; }
.chart-box { position: relative; width: 145px; height: 145px; margin: 0 auto; }
.chart-box svg { width: 100%; height: 100%; transform: rotate(-90deg); }
.bg-ring { fill: none; stroke: rgba(255, 255, 255, 0.1); stroke-width: 6; }
.fg-ring { fill: none; stroke-width: 6; stroke-linecap: round; stroke-dasharray: 283; stroke-dashoffset: 283; }
.weight-color { stroke: #10b981; filter: drop-shadow(0 0 6px rgba(16, 185, 129, 0.6)); } 
.channel-color { stroke: #3b82f6; filter: drop-shadow(0 0 6px rgba(59, 130, 246, 0.6)); } 
.pcb-color { stroke: #f59e0b; filter: drop-shadow(0 0 6px rgba(245, 158, 11, 0.6)); }    
.inner-content { position: absolute; top: 0; left: 0; right: 0; bottom: 0; display: flex; flex-direction: column; justify-content: center; align-items: center; }
.inner-content .label { font-size: 10px; font-weight: 700; color: #94a3b8; margin-bottom: 2px; }
.inner-content .number-container { display: flex; align-items: baseline; justify-content: center; }
.inner-content .number { font-family: 'JetBrains Mono', monospace; font-size: 32px; font-weight: 800; color: #ffffff; text-shadow: 0 2px 4px rgba(0,0,0,0.5); }
.inner-content .unit { font-size: 16px; font-weight: bold; color: #cbd5e1; margin-left: 2px; }
.inner-content .sub { font-size: 10px; color: rgba(148, 163, 184, 0.8); margin-top: 2px; }

@media (max-width: 600px) {
  .metrics-grid { gap: 6px; } 
  .metric-card.glass-panel { padding: 10px 2px; background: rgba(15, 23, 42, 0.92); backdrop-filter: none; -webkit-backdrop-filter: none; }
  .chart-box { width: 70px; height: 70px; }
  .inner-content .number { font-size: 18px; }
  .inner-content .unit { font-size: 11px; }
  .inner-content .label { font-size: 8px; font-family: sans-serif !important; letter-spacing: 0 !important; }
  .inner-content .sub { display: none; }
  .gesture-hud { backdrop-filter: none; -webkit-backdrop-filter: none; background: rgba(15, 23, 42, 0.75); }
}

/* ====== Publication Card ====== */
.pub-section { max-width: 760px; margin: 40px auto; }

.pub-card {
  background: rgba(11, 17, 33, 0.95);
  border: 1px solid rgba(59, 130, 246, 0.25);
  border-radius: 20px;
  padding: 28px 32px;
  box-shadow: inset 0 0 20px rgba(0,0,0,0.4), 0 15px 40px rgba(0,0,0,0.2);
  position: relative;
  overflow: hidden;
}
.pub-card::before {
  content: '';
  position: absolute;
  top: 0; left: 8%; right: 8%;
  height: 2px;
  background: linear-gradient(90deg, #3b82f6, #a78bfa, #f472b6);
  border-radius: 0 0 4px 4px;
  opacity: 0.7;
}

.pub-header {
  display: flex; align-items: center; gap: 10px;
  margin-bottom: 14px; flex-wrap: wrap;
}
.pub-journal {
  font-family: 'JetBrains Mono', monospace;
  font-size: 12px; font-weight: 700; color: #93c5fd;
  letter-spacing: 1.2px; text-transform: uppercase;
}
.pub-badge {
  font-family: 'JetBrains Mono', monospace;
  font-size: 10px; padding: 3px 10px;
  border-radius: 10px; font-weight: 700; letter-spacing: 0.5px;
}
.pub-badge.status {
  background: rgba(16, 185, 129, 0.15); color: #34d399;
  border: 1px solid rgba(16, 185, 129, 0.3);
}
.pub-badge.year {
  background: rgba(59, 130, 246, 0.12); color: #93c5fd;
  border: 1px solid rgba(59, 130, 246, 0.3);
}

.pub-title {
  font-size: 18px; font-weight: 700; color: #f1f5f9;
  line-height: 1.4; margin: 0 0 10px 0;
}
.pub-authors {
  font-size: 13px; color: #cbd5e1;
  margin-bottom: 6px; line-height: 1.6;
}
.pub-authors em {
  color: #93c5fd; font-style: normal; font-weight: 600;
}

.pub-cite {
  font-family: 'JetBrains Mono', monospace;
  font-size: 11.5px; color: #94a3b8;
  background: rgba(0, 0, 0, 0.25);
  border: 1px solid rgba(255, 255, 255, 0.06);
  border-radius: 8px; padding: 10px 14px;
  margin: 14px 0 18px; line-height: 1.55; word-break: break-word;
}
.pub-cite a {
  color: #60a5fa; text-decoration: none;
  border-bottom: 1px dashed rgba(96, 165, 250, 0.4);
}

.pub-actions {
  display: grid; grid-template-columns: 1fr 1fr;
  gap: 10px; margin-bottom: 14px;
}
.pub-btn {
  display: flex; align-items: center; justify-content: center;
  gap: 8px; padding: 11px 16px; border-radius: 10px;
  font-family: 'JetBrains Mono', monospace;
  font-size: 13px; font-weight: 700;
  text-decoration: none; letter-spacing: 0.5px;
  transition: all 0.3s cubic-bezier(0.25, 0.8, 0.25, 1);
  border: 1px solid; cursor: pointer;
}
.pub-btn.primary {
  background: linear-gradient(135deg, rgba(59, 130, 246, 0.2), rgba(96, 165, 250, 0.1));
  border-color: rgba(59, 130, 246, 0.5); color: #93c5fd;
  box-shadow: 0 0 18px rgba(59, 130, 246, 0.15);
}
.pub-btn.primary:hover {
  background: linear-gradient(135deg, rgba(59, 130, 246, 0.35), rgba(96, 165, 250, 0.2));
  border-color: #60a5fa; color: #ffffff;
  transform: translateY(-2px);
  box-shadow: 0 8px 25px rgba(59, 130, 246, 0.3);
}
.pub-btn.secondary {
  background: rgba(167, 139, 250, 0.1);
  border-color: rgba(167, 139, 250, 0.4); color: #c4b5fd;
}
.pub-btn.secondary:hover {
  background: rgba(167, 139, 250, 0.2);
  border-color: #a78bfa; color: #ffffff;
  transform: translateY(-2px);
  box-shadow: 0 8px 25px rgba(167, 139, 250, 0.25);
}

.pub-disclaimer {
  font-size: 10px; color: rgba(148, 163, 184, 0.6);
  line-height: 1.5; padding-top: 14px;
  border-top: 1px solid rgba(255, 255, 255, 0.06);
  font-family: system-ui, sans-serif;
}
.pub-disclaimer strong { color: rgba(203, 213, 225, 0.8); }

/* Light mode */
body.light-mode .pub-card {
  background: #ffffff; border-color: #cbd5e1;
  box-shadow: 0 15px 40px rgba(0,0,0,0.05);
}
body.light-mode .pub-journal { color: #2563eb; }
body.light-mode .pub-title { color: #0f172a; }
body.light-mode .pub-authors { color: #334155; }
body.light-mode .pub-authors em { color: #2563eb; }
body.light-mode .pub-cite {
  background: #f8fafc; color: #475569; border-color: #e2e8f0;
}
body.light-mode .pub-disclaimer { color: #64748b; }
body.light-mode .pub-disclaimer strong { color: #334155; }

/* Mobile */
@media (max-width: 600px) {
  .pub-card { padding: 22px 18px; }
  .pub-actions { grid-template-columns: 1fr; }
  .pub-title { font-size: 16px; }
  .pub-cite { font-size: 10.5px; padding: 8px 12px; }
}
    
/* ===================== 高级 3D 封面特效 (HUD) ===================== */
.cyber-loader { position: relative; width: 50px; height: 50px; }
.cyber-loader::before, .cyber-loader::after { content: ''; position: absolute; border-radius: 50%; }
.cyber-loader::before { top: 0; left: 0; right: 0; bottom: 0; border: 2.5px solid transparent; border-top-color: #60a5fa; border-bottom-color: #60a5fa; animation: spin 1.5s cubic-bezier(0.68, -0.55, 0.265, 1.55) infinite; box-shadow: 0 0 10px rgba(96, 165, 250, 0.5); }
.cyber-loader::after { top: 8px; left: 8px; right: 8px; bottom: 8px; border: 2px solid transparent; border-left-color: #3b82f6; border-right-color: #3b82f6; animation: spin-reverse 1s linear infinite; }
@keyframes spin-reverse { to { transform: rotate(-360deg); } }

.hud-corner { position: absolute; width: 25px; height: 25px; border: 2px solid rgba(96, 165, 250, 0.6); box-shadow: 0 0 8px rgba(59, 130, 246, 0.4); }
.hud-tl { top: 20px; left: 20px; border-right: none; border-bottom: none; }
.hud-tr { top: 20px; right: 20px; border-left: none; border-bottom: none; }
.hud-bl { bottom: 20px; left: 20px; border-right: none; border-top: none; }
.hud-br { bottom: 20px; right: 20px; border-left: none; border-top: none; }

.scanline { position: absolute; top: 0; left: 0; width: 100%; height: 3px; background: linear-gradient(90deg, transparent, rgba(96, 165, 250, 0.8), transparent); box-shadow: 0 0 15px rgba(59, 130, 246, 0.8); animation: scan-sweep 3s linear infinite; opacity: 0.6; }
@keyframes scan-sweep { 0% { top: 0; opacity: 0; } 10% { opacity: 0.6; } 90% { opacity: 0.6; } 100% { top: 100%; opacity: 0; } }

.nav-badges a { display: inline-block; transition: all 0.3s cubic-bezier(0.25, 0.8, 0.25, 1); margin: 0 2px; }
.nav-badges a:hover { transform: translateY(-3px) scale(1.05); filter: drop-shadow(0 5px 8px rgba(59, 130, 246, 0.4)); }
.nav-badges a:active { transform: translateY(0) scale(0.98); }
.click-to-load-glow { cursor: pointer; transition: all 0.3s ease; }
.click-to-load-glow:hover { transform: scale(1.05); text-shadow: 0 0 15px rgba(96, 165, 250, 1); }
</style>
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

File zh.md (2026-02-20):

---
layout: default
title: E-Link 中文首页
permalink: /zh/
---

<link rel="preconnect" href="https://fonts.googleapis.com">
<link rel="preconnect" href="https://fonts.gstatic.com" crossorigin>

<link rel="stylesheet" href="{{ '/assets/css/elink-custom.css' | relative_url }}">
<script src="{{ '/assets/js/elink-custom.js' | relative_url }}" defer></script>

<div class="lang-zh" markdown="1">

<div align="center" class="nav-badges">
  
  
  
  
  
  
</div>
  
<div align="center" style="margin-bottom: 20px;">
  <h1 class="header-sync-pulse bi-color-title" style="display: flex; align-items: center; justify-content: center; border-bottom: none; margin-bottom: 5px; font-size: 2.2em; font-weight: 800; letter-spacing: -1px; font-family: 'Inter', 'Noto Sans SC', sans-serif;">
    
    <svg width="45" height="45" viewBox="0 0 24 24" fill="none" xmlns="http://www.w3.org/2000/svg" style="margin-right: 15px;">
      <path d="M10 13a5 5 0 0 0 7.54.54l3-3a5 5 0 0 0-7.07-7.07l-1.72 1.71" stroke="url(#icon-gradient-zh)" stroke-width="2.5" stroke-linecap="round" stroke-linejoin="round"/>
      <path d="M14 11a5 5 0 0 0-7.54-.54l-3 3a5 5 0 0 0 7.07 7.07l1.71-1.71" stroke="url(#icon-gradient-zh)" stroke-width="2.5" stroke-linecap="round" stroke-linejoin="round"/>
      <defs>
        <linearGradient id="icon-gradient-zh" x1="0%" y1="0%" x2="100%" y2="100%">
          <stop offset="0%" stop-color="#60a5fa" />
          <stop offset="50%" stop-color="#a78bfa" />
          <stop offset="100%" stop-color="#f472b6" />
        </linearGradient>
      </defs>
    </svg>

    E-Link(易链256)
  </h1>
</div>

<h2 class="sub-title">
  一种基于弹性导电体互连技术的<br class="mobile-only-br">高密度柔性神经接口连接器
</h2>
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

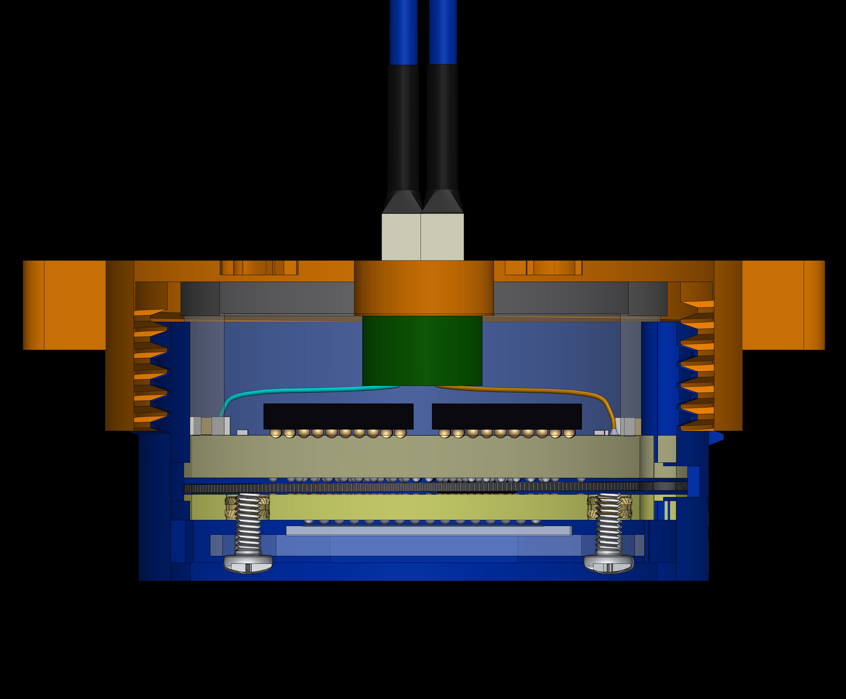
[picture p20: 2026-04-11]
Images/Assem new.PNG

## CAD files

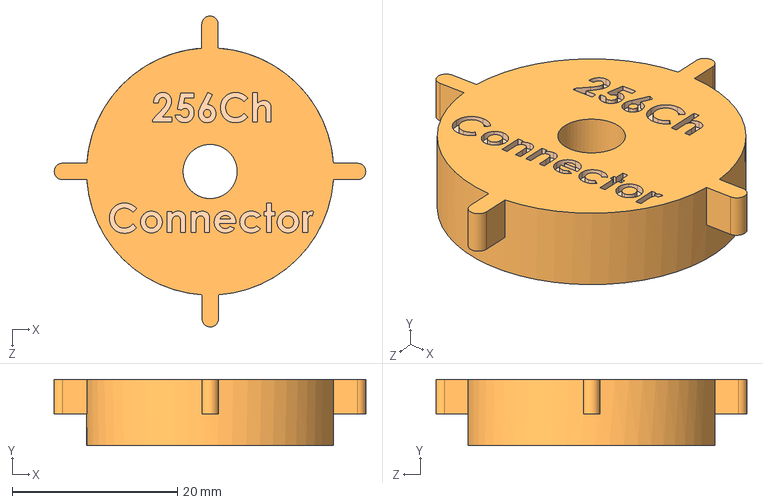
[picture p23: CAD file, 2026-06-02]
Housing and Cap/Cap.STEP
37.8 x 8.00 x 37.7 mm

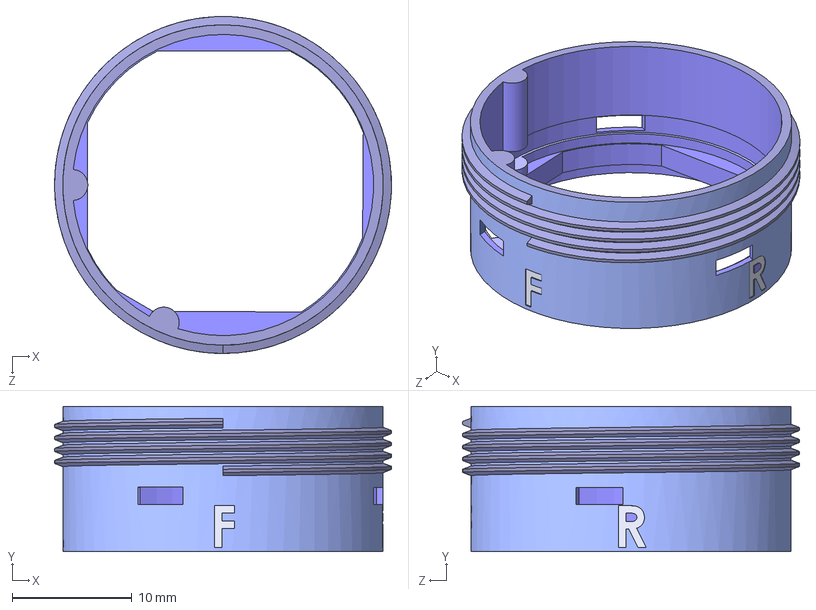
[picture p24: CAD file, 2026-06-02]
Housing and Cap/Pedestal Housing.STEP
28.2 x 12.2 x 28.2 mm

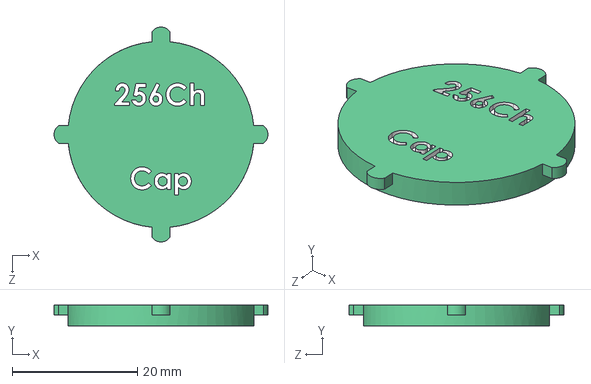
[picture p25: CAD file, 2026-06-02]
Housing and Cap/Dustproof Protective Cap (non-recording session use).STEP
34.2 x 3.30 x 34.4 mm

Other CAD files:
Housing and Cap/Cap.STL
Housing and Cap/Dustproof Protective Cap (non-recording session use).STL
Housing and Cap/Pedestal Housing.STL

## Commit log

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2026-01-26 Enhance README with structured tables
    Updated the README to include formatted tables for specifications, system components, and bill of materials.
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2026-01-27 Implement progress bar and improve button effects
    Add a top progress bar and enhance button animations.
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2026-02-02 Remove SVG filter from default layout
    Removed unused SVG filter definition from layout.
2026-02-02 Refactor bot layout and positioning for better UX
    Adjusted layout and positioning for the bot container and dialogue to improve visibility and responsiveness on both PC and mobile devices.
2026-02-02 Revise E-Link overview for clarity and conciseness
    Updated the overview section to clarify the purpose and features of the E-Link connector.
2026-02-03 Enhance welcome modal with language toggle feature
    Added language toggle button to the welcome modal and improved text for better clarity. Adjusted styles and interactions for the modal and language switching functionality.
2026-02-03 Revise E-Link overview and specifications
    Updated descriptions and terminology for the E-Link connector system in both English and Chinese sections. Adjusted image alt text and refined BOM and publication details.
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2026-02-05 Update index.md with amplifier image and details
    Added image and description for the assembled 256-channel amplifier.
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2026-02-07 Enhance RHD Connector interactive 3D view
    Updated the RHD Connector section to enhance the interactive 3D view with additional styling and instructions.
2026-02-07 Enhance video modal and add bilingual support
    Updated video modal styles and added bilingual dialog data for the Connector Guardian feature.
2026-02-12 Refactor gesture HUD and add reset button styles
    Updated styles for gesture HUD and reset button. Added reset button functionality for 3D interactive views.
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2026-02-14 Improve interaction hints and pause logic
    Refactor interaction hints and timers for model viewer.
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2026-02-16 Enhance Vanta background for mobile optimization
    Optimize Vanta background settings for mobile devices and improve performance.
2026-02-16 Refactor Vanta settings and media loading strategy
    Updated Vanta background settings for better performance on mobile devices and adjusted loading strategies for GIFs and videos.
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2026-02-18 Enhance animation frame cancellation logic
    Optimize animation cleanup to prevent memory overflow.
2026-02-18 Enhance icon descriptions and glow effects
    Updated the description text for the 'Macaque' and '灵长类' sections to include colored formatting for 'Multi-Array Scalable' and '可拓展矩阵'. Adjusted glow effects for icons to increase visibility.
2026-02-18 Modify layout margins and media query styles
    Adjusted margin-top for better layout and updated media query padding and min-height for consistency across devices.
2026-02-23 Clarify overview of E-Link connector system
    Updated description to specify 'High-Density Soft Neural Interfaces' instead of 'flexible neural probes'.
2026-02-24 Fix GIF display and animation logic
    修复 GIF 显示和动画逻辑，调整视口触发点。
2026-02-25 Implement E-Link Dynamic Dashboard V2 styles and metrics
    Added new styles and components for E-Link Dynamic Dashboard V2, including metric cards for weight, channels, PCB layers, temperature, noise floor, and connection yield. Updated layout and animations for improved visualization.
2026-02-25 Enhance V2 dashboard with responsive styles
    Added responsive styles for V2 dashboard metrics and adjusted layout for better display on mobile devices.
2026-02-25 Delete icon switching CSS for responsiveness
    Removed icon switching logic for desktop and mobile.
2026-02-26 Enhance layout and drawing logic for mobile support
    Refactor CSS styles for layout responsiveness and improve canvas drawing logic for mobile devices. Adjustments include dynamic sizing for elements, ensuring proper rendering on different screen width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
2026-02-26 Enhance Intan filter and software filtering UI
    Added new styles and functionality for Intan filter and software filtering panels, including radio buttons and selection options.
2026-02-26 Refactor Intan filter panel and improve mobile support
    Removed old Intan filter panel styles and added new filter bandwidth settings. Updated sampling rate display and adjusted canvas rendering logic for mobile responsiveness.
2026-02-26 Implement Intan hardware control panel features
    Added styles and functionality for the Intan hardware control panel, including filter display selectors and software filtering options.
2026-02-26 Update layout and filter settings in index.md
    Refactor Intan panel layout and update filter display settings.
2026-02-26 Refactor generateChannels function for ECoG settings
    Updated the impedance settings for normal ECoG channels to be between 366-466 kΩ and adjusted the channel color assignment based on bad channel detection.
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2026-03-01 Refactor SPI boot-up styles and update port statuses
    Removed unused SPI boot-up animation styles and logic. Updated hardware port titles and statuses.
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2026-03-03 Enhance custom model viewer with frosted glass effect
    Updated the custom model viewer styles to include a frosted glass effect with a backdrop filter and enhanced box shadow.
2026-03-03 Refactor light mode styles and cursor behavior
    Refactor light mode styles and cursor behavior for better user experience on mobile devices. Adjust particle count and add typewriter timeout handling.
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2026-03-06 Improve spike generation with noise and jitter effects
    Refactor spike generation function to enhance realism with noise and jitter effects.
2026-03-07 JS performance optimizations: fix frame drops, GPU waste, and race conditions
2026-03-07 Refactor noise generation for bad channels
    Refactor power line interference generation and adjust noise levels for bad channels.
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2026-04-12 Fix Headstage PCB description in index.md
    Corrected the description of the Headstage PCB.
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

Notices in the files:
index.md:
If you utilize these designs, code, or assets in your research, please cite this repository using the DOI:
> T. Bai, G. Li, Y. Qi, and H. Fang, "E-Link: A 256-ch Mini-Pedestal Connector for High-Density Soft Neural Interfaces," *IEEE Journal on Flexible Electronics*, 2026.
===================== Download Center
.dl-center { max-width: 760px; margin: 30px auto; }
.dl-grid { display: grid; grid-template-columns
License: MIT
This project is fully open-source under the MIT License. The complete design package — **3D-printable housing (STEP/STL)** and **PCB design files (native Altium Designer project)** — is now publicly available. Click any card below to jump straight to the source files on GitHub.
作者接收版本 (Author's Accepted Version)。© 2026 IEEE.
